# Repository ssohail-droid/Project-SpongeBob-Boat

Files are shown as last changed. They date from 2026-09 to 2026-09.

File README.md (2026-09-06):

# Project: SpongeBob Boat

A budget build (under $250) using recycled and scrap parts, designed to resemble SpongeBob's boat while carrying one driver and one passenger a distance of 2 miles over varying inclines and declines.

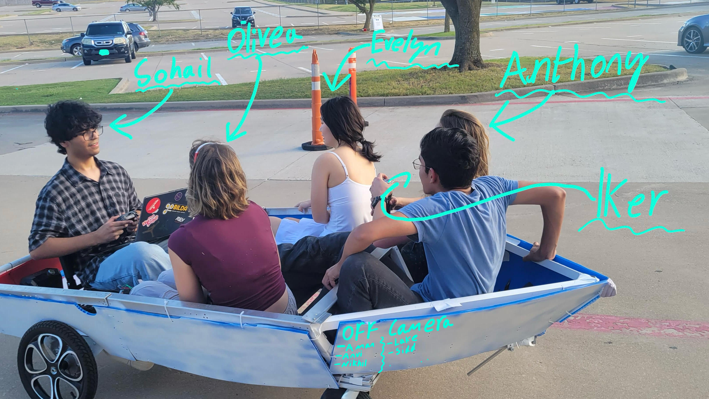
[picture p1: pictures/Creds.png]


# Design Requirements
- Total budget under $250
- Visual theme matching SpongeBob's boat
- Capacity for one driver and one passenger
- Must travel 2 miles over varying terrain grade (inclines and declines)

# Approach

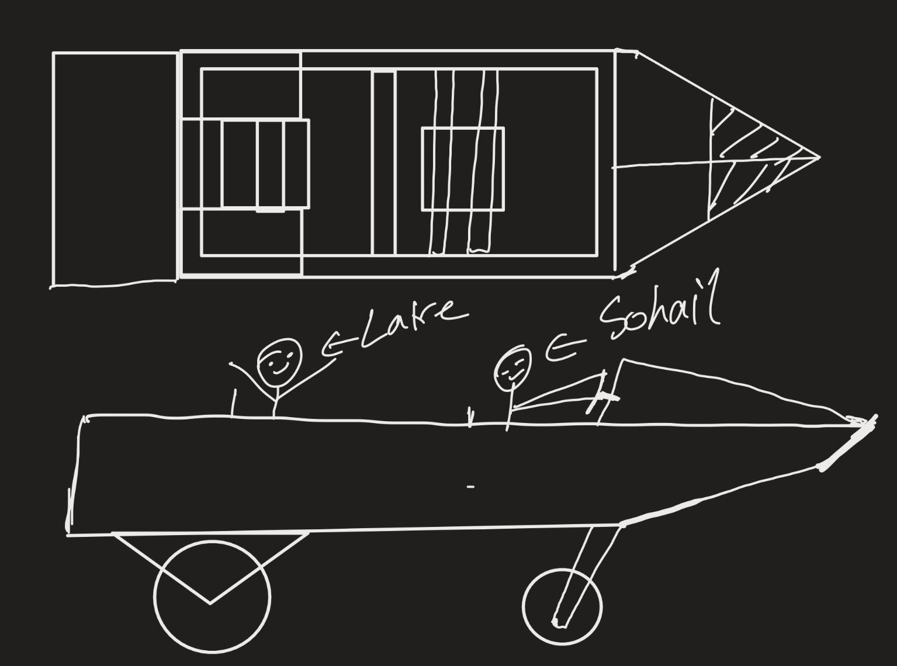
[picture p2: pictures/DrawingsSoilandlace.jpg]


The initial priority was structural: build a frame capable of safely supporting two riders and driving reliably, before addressing aesthetics. We began with a rectangular 40x40 aluminum extrusion frame reinforced with a center beam for added rigidity.

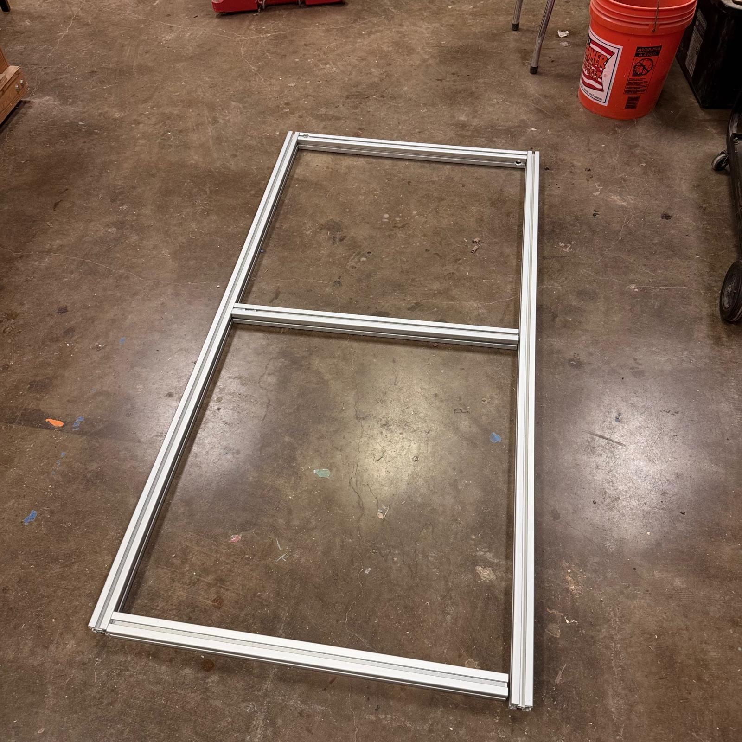
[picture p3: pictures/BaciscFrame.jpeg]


This design gave us a frame rigid enough to support two passengers (~400 lbs combined load). The frame was assembled using plasma-cut 90° brackets, slotted T-nuts, and M6 hardware throughout.

<p align="center">
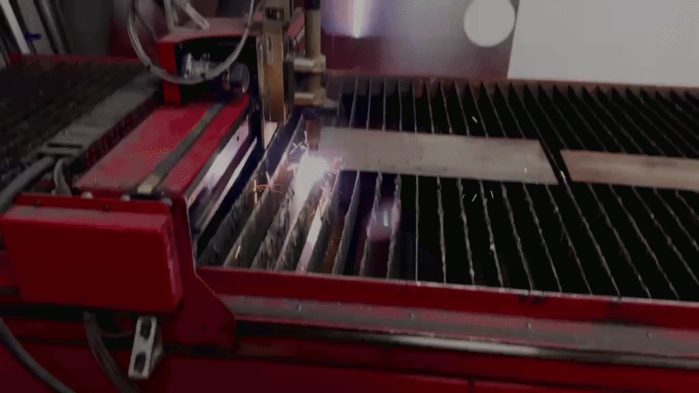
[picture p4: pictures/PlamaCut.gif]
SpongeBob Boat demo
  
</p>

Motor brackets were plasma-cut from 1/8" mild steel to mount a recycled wheelchair motor — a 24V, 250W high-torque unit repurposed for propulsion.

<p align="center">
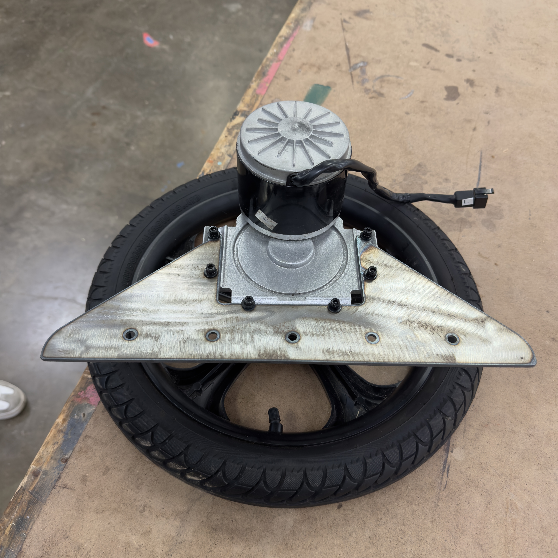
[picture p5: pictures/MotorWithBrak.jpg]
  
</p>

At this stage, the chassis was fully assembled and structurally rigid.

<p align="center">
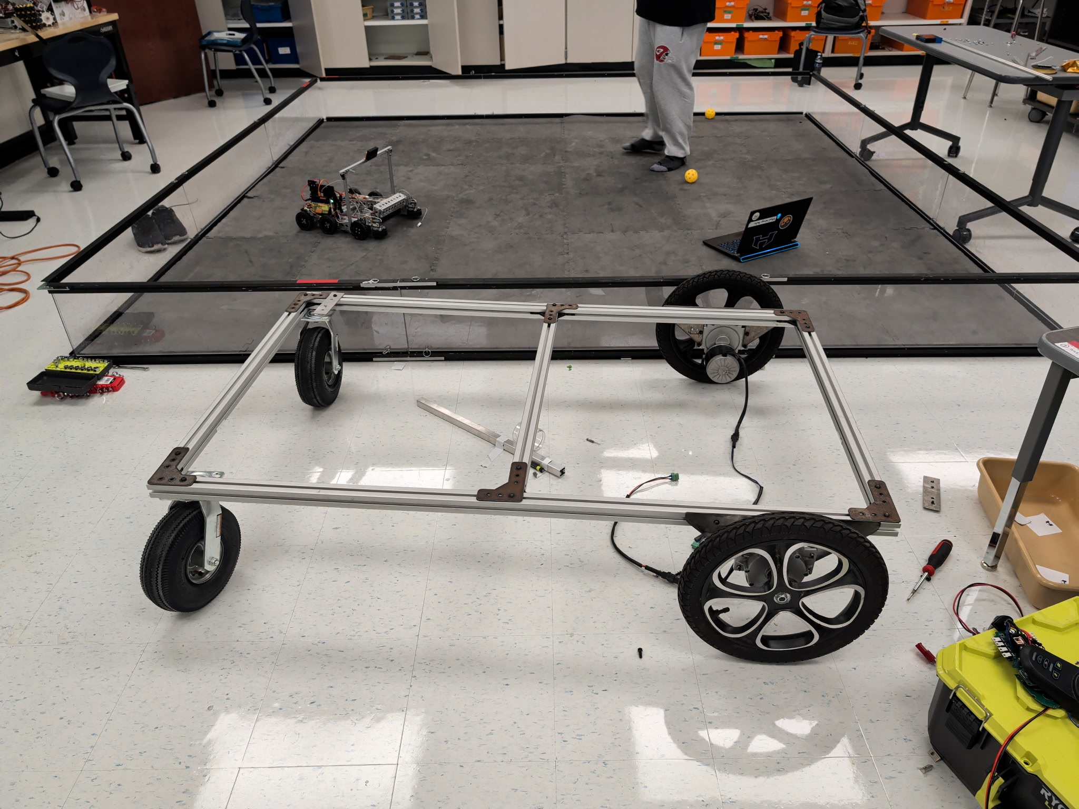
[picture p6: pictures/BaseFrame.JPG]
  
</p>

One issue that emerged was **canting** — where the wheel angles outward under load, bending the mounting bracket over time.

<p align="center">
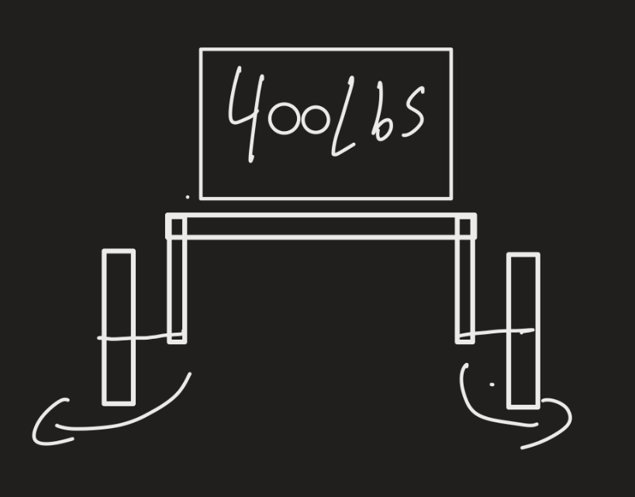
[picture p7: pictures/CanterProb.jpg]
  
</p>

The fix was a simple structural brace: adding a support bar between the two motor mounts. This tied the mounts together and significantly reduced canting under load.

<p align="center">
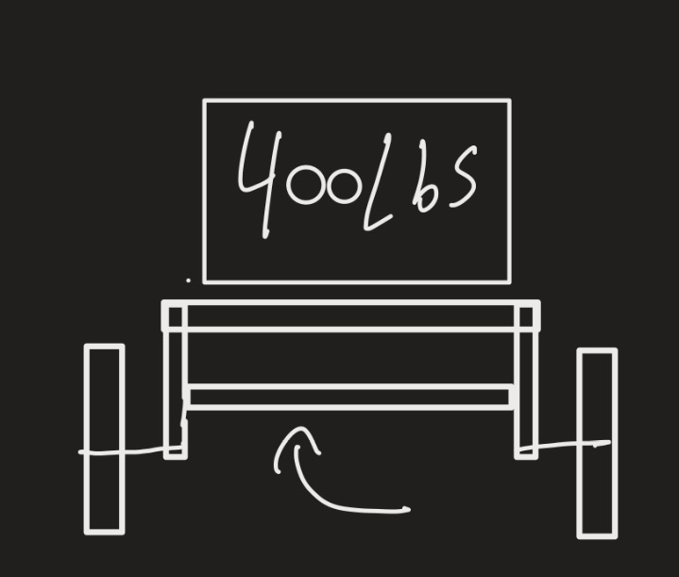
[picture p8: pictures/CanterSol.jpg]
  
</p>

## Powertrain and Electronics

Originally, we used the control unit salvaged from the wheelchair, but this proved unreliable — it produced constant errors and overheated under load.

<p align="center">
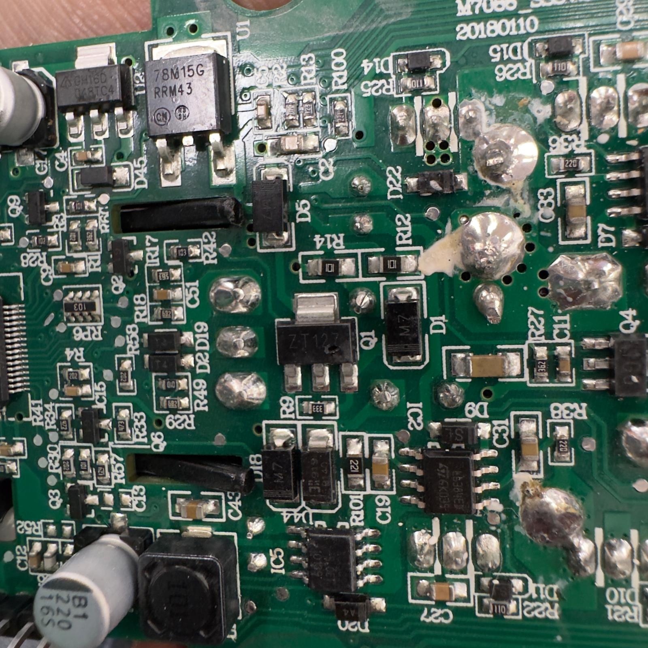
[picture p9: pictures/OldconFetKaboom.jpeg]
  
</p>

Our fallback was the BTS7960 high-current motor driver. It was the perfect choice for this build due to its high current rating and low cost — rated for up to 43A, well above the ~20A per motor we see at max load.

<p align="center">
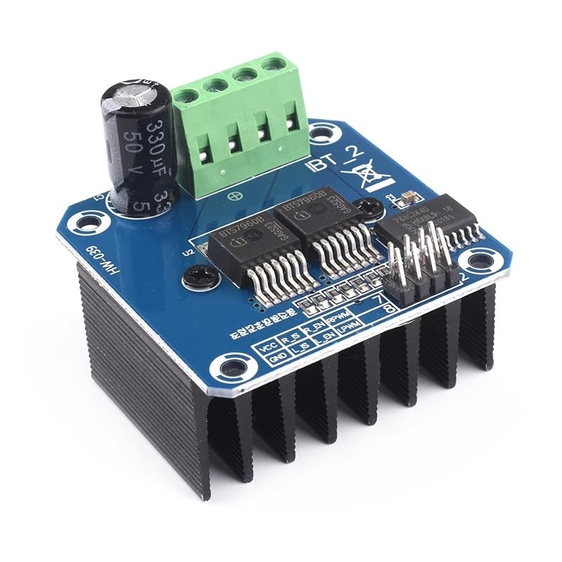
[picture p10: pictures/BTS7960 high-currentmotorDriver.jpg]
  
</p>

# Control System Architecture

The boat's drive system is split into two main units: the **MDU (Motor Drive Unit)** on the boat itself, and the **OCU (Operator Control Unit)** used by the driver.

## MDU (Motor Drive Unit)

The MDU handles all propulsion and power delivery on board the boat:

- **Motors:** Two 250W 24V DC motors provide propulsion.
- **Motor Drivers:** Each motor is controlled by its own BTS7960 driver module, allowing independent speed and direction control per side (differential drive).
- **Battery:** A 24V 36Ah battery pack supplies power to both motors and the driver boards.
- **Controller:** An Arduino UNO reads control commands and sends PWM/direction signals to the two BTS7960 drivers, translating input into motor output.

## OCU (Operator Control Unit)

The OCU is the driver-facing control setup:

- A **Logitech gamepad** connects via **USB** to a laptop.
- The laptop reads gamepad input and sends drive commands to the Arduino UNO over **UART** (serial connection).

## Signal Flow

The laptop acts as the bridge between operator input and the motor control unit, translating joystick movement from the gamepad into serial commands that the Arduino interprets and forwards to the motor drivers.

<p align="center">
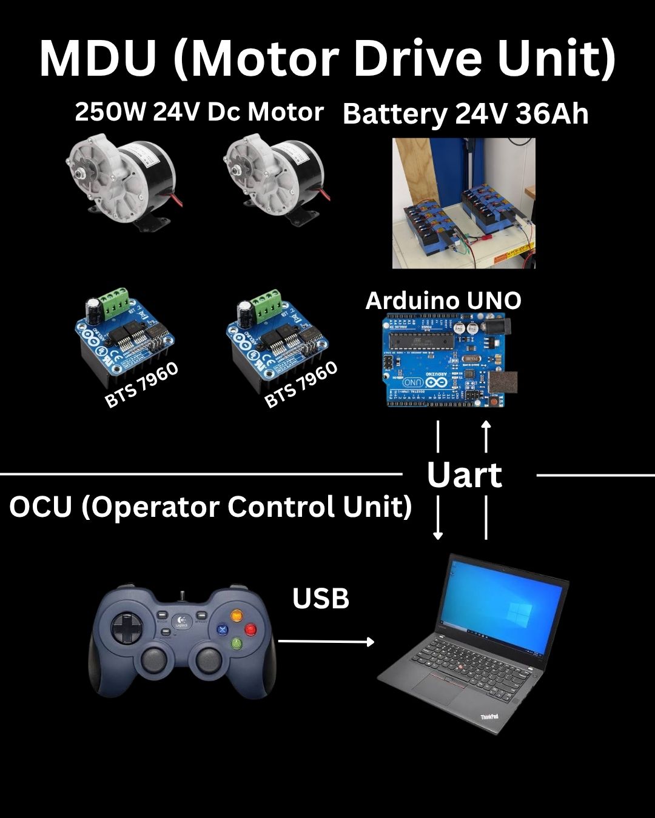
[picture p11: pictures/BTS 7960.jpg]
  
</p>

## Testing

<p align="center">
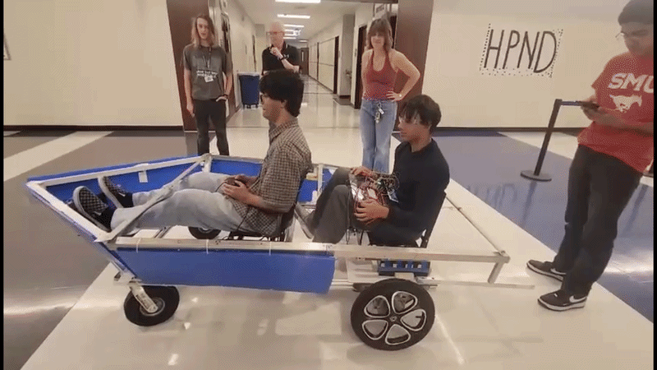
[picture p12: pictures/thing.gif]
  
</p>

## Problems and Solutions
- During testing, the battery wires heated up due to the 40A draw. Switching from 14 AWG to 8 AWG wire resolved the overheating.
- Another unexpected issue: bundled wires were acting as an electromagnet. Separating the wires fixed this.

## Results
- To be decided.

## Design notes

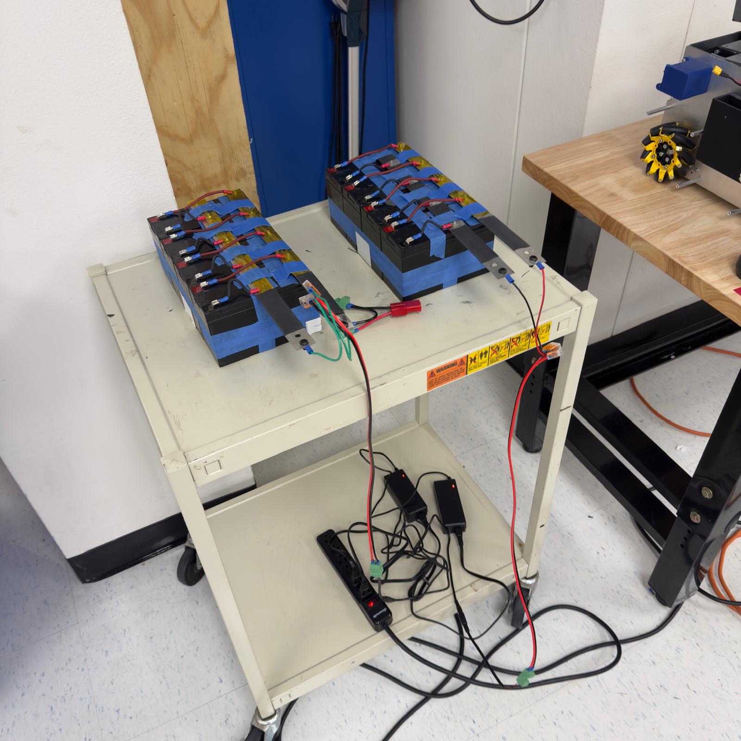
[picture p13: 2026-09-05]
pictures/BattryPack.jpeg

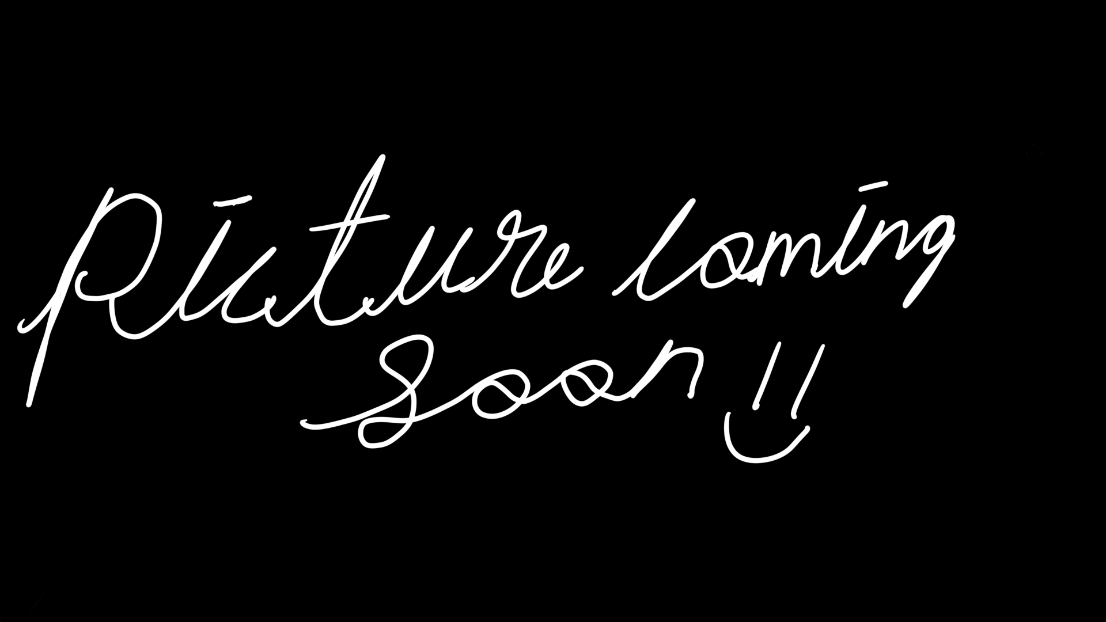
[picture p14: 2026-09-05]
pictures/missing.PNG

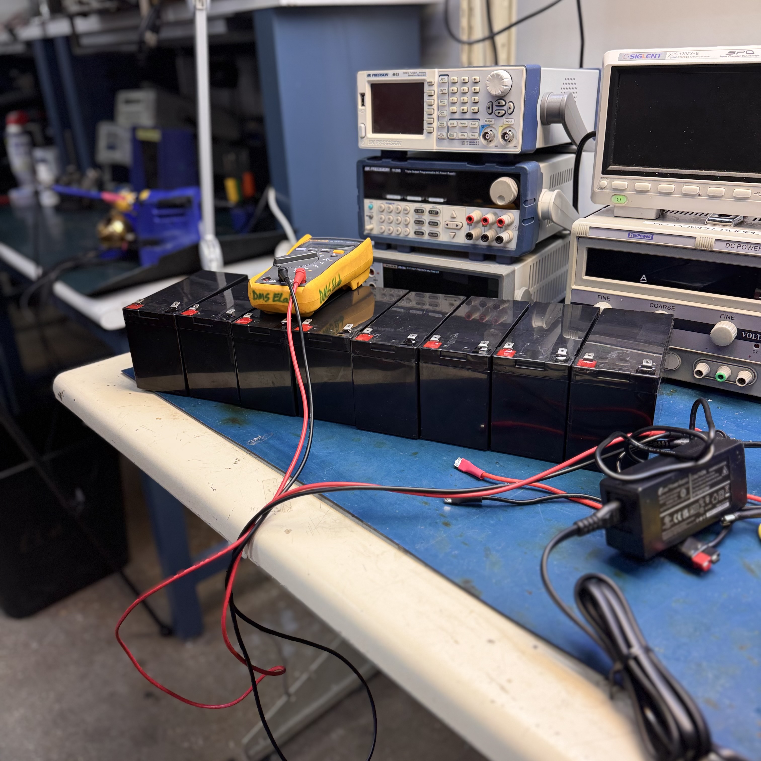
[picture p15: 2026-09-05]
pictures/Battrys.jpeg

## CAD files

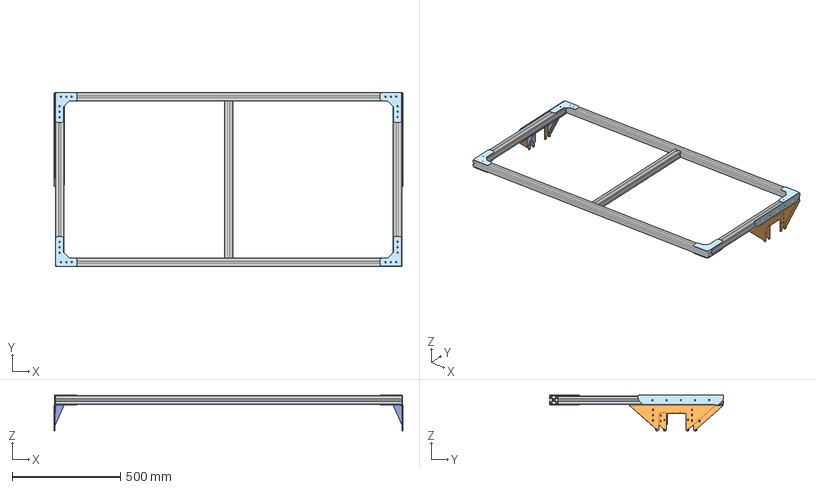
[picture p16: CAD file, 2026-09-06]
CAD/MainChassis.step
1612.1 x 804.6 x 166.3 mm

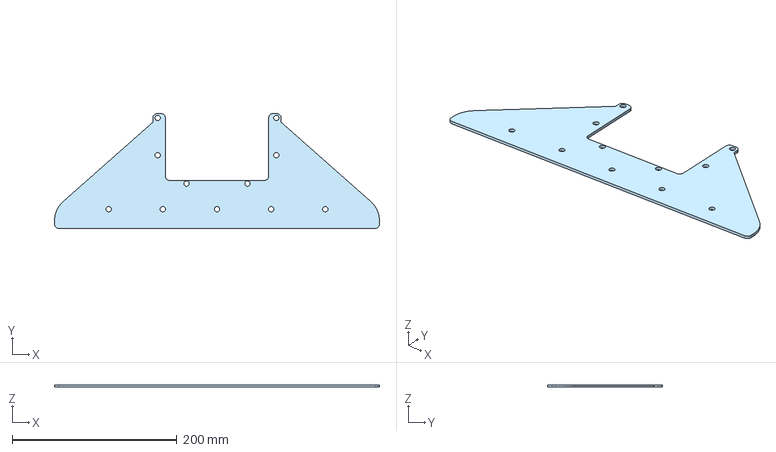
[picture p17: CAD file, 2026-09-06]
CAD/Motor Bracket.step
394.5 x 139.2 x 3.00 mm

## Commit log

2026-09-06 Add details about chassis and canting solutions
2026-09-06 Update README with PowerTrane and Electronics section
    Added section about PowerTrane and Electronics with images.
2026-09-06 Update README with BTS7960 motor driver details
    Added information about the BTS7960 high-current motor driver and its specifications.
2026-09-06 Update README to clarify signal flow details
    Clarify the role of the laptop in the signal flow between the gamepad and motor control unit.
2026-09-06 Revise README for Powertrain details and add troubleshooting
    Updated the Powertrain and Electronics section for clarity and conciseness. Added a new Problems and Solutions section detailing issues encountered during testing.
2026-09-06 Add gamepad control for Arduino tank drive
    This script allows control of an Arduino Uno tank drive using a USB gamepad. It includes deadzone handling and serial communication for speed control.
2026-09-06 Add Arduino code for tank drive control
2026-09-06 Add new file CAD/Text with content 'E'
